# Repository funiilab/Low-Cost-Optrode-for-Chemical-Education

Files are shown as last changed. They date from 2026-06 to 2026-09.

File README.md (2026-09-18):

# Low-Cost Optrode - Assistive Technology for Flexible Representation of Chemical Visual Indicators

DOI:

This project consist of a low-cost optrode based on out-the-shelf LEDs, for measure chemical visual indicators
transmittance to adapt the color changing to others stimuli.

## Components

- **Optrode**: Colorimetric sensor that will be immersed in solution to measure the color changing. 
   - *files*: 3D model (.stl), circuit diagram (.png).
- **Arduino**: Microcontroller responsible to measure the LED photovoltage, proportional to color intensity, and realize a digital filtering.
   - *files*: Code (.ino).
- **JavaScript**: Application responsible to communicate with the Arduino board and transform the color data in other stimuli.
   - **server.js**: Read serial port data in real time.
   - **sound.js**: Modulate a C-major chord.
   - **illustration.js**: Modulate proportion of OH⁻, H₃O⁺, H₂O molecules illustrated.
   - **index.html**: Main HTML entry point
   - **package.json**: Node.js dependencies
- **package-lock.json and package.json**: npm configuration files

## Requirements

### Hardware

The hardware consists of a microcontroller (Arduino) connected to two LEDs: one connected to an output pin, which serves as the light source, and the other connected to an input pin, which acts as the sensor.
The optrode can be constructed using different types of LEDs and microcontrollers with these capabilities. A resistor is used to adjust the voltage supplied to the light-source LED, while a capacitor is used to filter noise from the sensor signal.

The following is a list of the components and their prices required to build one optrode and the price of the microcontroller used in the work:
| Component | Units | Price (USD) | Part Number (DigiKey) |
| --- | --- | --- | --- |
| Arduino UNO R4 Minima | 1 | 20.00 | ABX00080|
| 5 mm LED | 2 | 0.18 | C503B-RAN-CZ0C0AA1 |
| 130 $\Omega$ Resistor | 1 | 0.10 | CFR-50JB-52-130R |
| 10 nF Capacitor | 1 | 0.27 | K104K15X7RF53K2 |
| Anycubic Standard Resin | 14 g | 19.99 / kg | |
| **Total (USD):** | | 21.01 |

### Software

- Node.js (v14 or higher)
- Web browser with WebSocket support (Chrome, Firefox, Safari, Edge)
- npm (Node Package Manager)

## Installation

### 1. Install Dependencies

```bash
npm install
```

This installs:
- `ws`: WebSocket server library
- `serialport`: Arduino serial port communication

### 2. Configure Serial Port

Edit `server.js` and update these variables to match your setup:
```javascript
const SERIAL_PORT_PATH = 'COM3';        // Change to your Arduino port (COM3, COM4, etc. on Windows)
const SERIAL_BAUD_RATE = 9600;          // Match your Arduino baud rate
```

**Finding your Arduino port:**
- **Windows**: Device Manager → Ports (COM & LPT) → Look for Arduino COM port
- **macOS**: `ls /dev/tty.*` in terminal (usually `/dev/tty.usbserial-*`)
- **Linux**: `ls /dev/tty*` in terminal (usually `/dev/ttyUSB0` or `/dev/ttyACM0`)

### 3. Start the Server

```bash
npm start
```

### 4. Open Visualization in Browser

Open `index.html` directly in your file manager

## Configuration

### Sensor Calibration

Each visualization file (`.js`) has configurable constants at the top that control behavior:

**rascunho3.js (Particle Visualization)**
```javascript
const MIN_SERIAL_VALUE = 3400;           // Sensor value at acidic end
const MAX_SERIAL_VALUE = 3900;           // Sensor value at basic end
const MEAN_SERIAL_VALUE = 3600;          // Neutral pH point
```

**rascunhoPrint.js & rascunhoI3.js (Audio Visualization)**
```javascript
const MIN_SERIAL_VALUE = 4600;           // Sensor value for min frequency
const MAX_SERIAL_VALUE = 2100;           // Sensor value for max frequency
const MIN_FILTER_FREQ = 200;             // Minimum filter frequency (Hz)
const MAX_FILTER_FREQ = 1000;            // Maximum filter frequency (Hz)
```

### Customizing Visualizations

Edit these constants to modify behavior:

| Variable | Effect |
|---|---|
| `TOTAL_PARTICLES` | Number of particles to display (higher = more CPU usage) |
| `CONSTANT_H2O` | Number of fixed water molecules (pH-independent) |
| `MOLECULE_SCALE` | Size multiplier for particle drawing |
| `INITIAL_NOTES` | Starting chord (e.g., `["C4", "E5", "G6"]`) |
| `MIN_FILTER_FREQ` | Lowest audio cutoff frequency |
| `MAX_FILTER_FREQ` | Highest audio cutoff frequency |

## How to change the stimulus
1. Open `index.html` in a text editor
2. Change the `.js` file in the line 13 (illustration.js or sound.js)
3. `Ctrl + S` to save
4. Open `index.html` in a browser

> :bulb: **Tip:** You can create your own stimuli using JavaScript!

## Authors

Lead: Takahara dos Santos (takahara.santos@usp.br)

PI: Gabriel N. Meloni  (gabriel.meloni@usp.br)

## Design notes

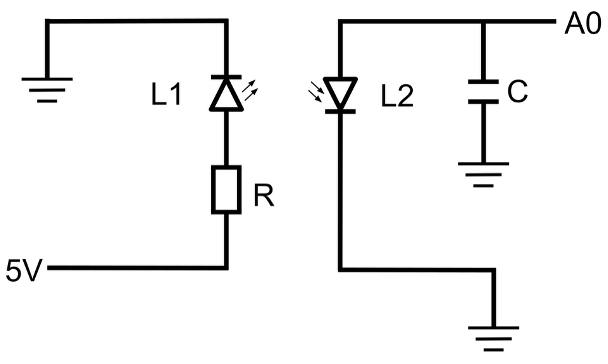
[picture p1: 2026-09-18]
Optrode/circuit_diagram.png

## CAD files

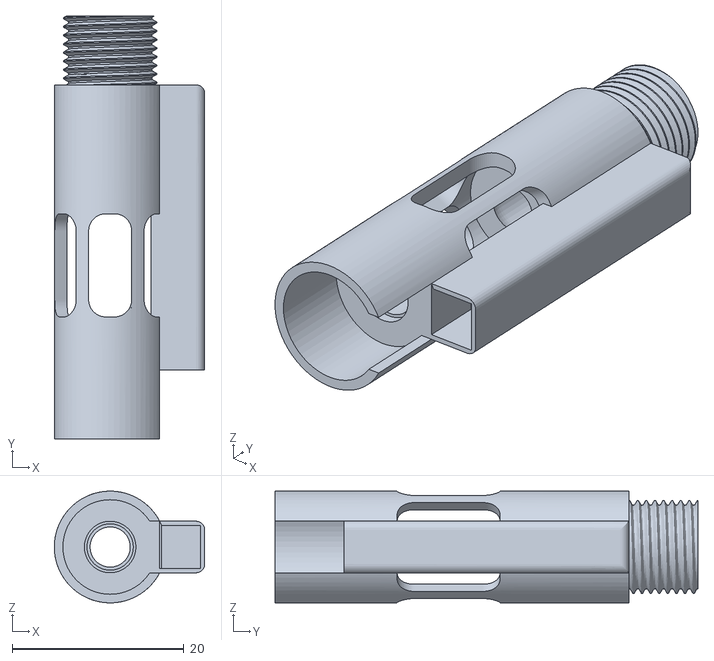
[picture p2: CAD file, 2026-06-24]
Optrode/Optrode_Head.stl
17.5 x 49.2 x 13.0

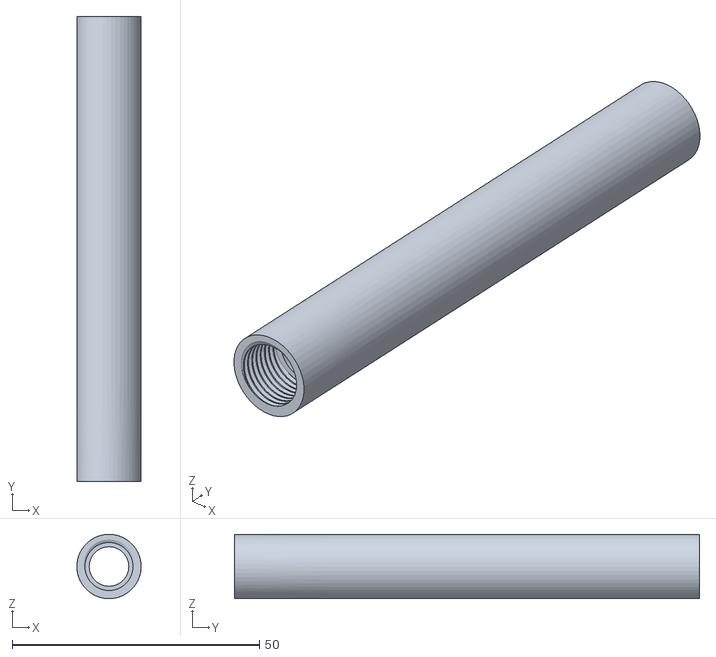
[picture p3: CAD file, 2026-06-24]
Optrode/Optrode_Body.stl
13.0 x 94.0 x 13.0

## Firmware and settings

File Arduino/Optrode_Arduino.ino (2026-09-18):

int mean = 0;
int nMeasures = 300;
long int totalMeasures = 0; 

void setup() {
  analogReadResolution(14); //set 14 bits of resolution (not able for all Arduino's boards)
  
  pinMode (A0, INPUT); //set A0 as sensor LED pin

  Serial.begin (9600);
}

void loop() {
  long int totalMeasures = 0; //reset total Measures

  //for-loop to add all measures in one variable
  for(int i = 0; i < nMeasures; i++){
    totalMeasures += analogRead (A0);
    delayMicroseconds(30);
  } 
  
  mean = totalMeasures / nMeasures; //mean calculation of all measures
  Serial.println(mean); //print mean value in seriar port
  
}

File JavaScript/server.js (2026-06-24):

/**
 * Serial Port to WebSocket Server
 * This server bridges Arduino serial data to web clients via WebSocket
 * allowing real-time sensor data visualization in the browser
 */

const WebSocket = require('ws');
const { SerialPort, ReadlineParser } = require('serialport');

// ===== CONFIGURATION VARIABLES =====
// Serial port settings
const SERIAL_PORT_PATH = 'COM5';        // Serial port path (change to your Arduino port)
const SERIAL_BAUD_RATE = 9600;          // Baud rate for serial communication
const SERIAL_DELIMITER = '\n';           // Line delimiter for serial data

// WebSocket server settings
const WEBSOCKET_PORT = 8080;             // WebSocket server port

// ===== SERIAL PORT CONFIGURATION =====
// Initialize serial port connection
const port = new SerialPort({ 
    path: SERIAL_PORT_PATH, 
    baudRate: SERIAL_BAUD_RATE 
});

// Create a readline parser to split incoming data by newline
const parser = port.pipe(new ReadlineParser({ delimiter: SERIAL_DELIMITER }));

// ===== WEBSOCKET SERVER SETUP =====
// Initialize WebSocket server
const wss = new WebSocket.Server({ port: WEBSOCKET_PORT });

console.log(`WebSocket server running on ws://localhost:${WEBSOCKET_PORT}`);
console.log(`Listening for serial data on ${SERIAL_PORT_PATH} at ${SERIAL_BAUD_RATE} baud`);

// ===== CONNECTION HANDLER =====
// Handle new WebSocket client connections
wss.on('connection', (ws) => {
    console.log('Client connected');

    // Listen for incoming serial data and forward to WebSocket clients
    parser.on('data', (data) => {
        // Check if connection is open before sending
        if (ws.readyState === WebSocket.OPEN) {
            ws.send(data.trim());  // Send trimmed data to client
        }
        console.log('Serial data:', data);
    });
    
    // Handle client disconnection
    ws.on('close', () => {
        console.log('Client disconnected');
    });
});

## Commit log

2026-09-18 Added: circuit diagram
2026-09-18 Update: circuit diagram, README improvement, npm install fix
    [Optrode_Body.stl, Optrode_Head.stl]
